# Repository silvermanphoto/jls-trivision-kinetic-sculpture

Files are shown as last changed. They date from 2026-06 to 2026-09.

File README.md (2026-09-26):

# Trivision Kinetic Sculpture

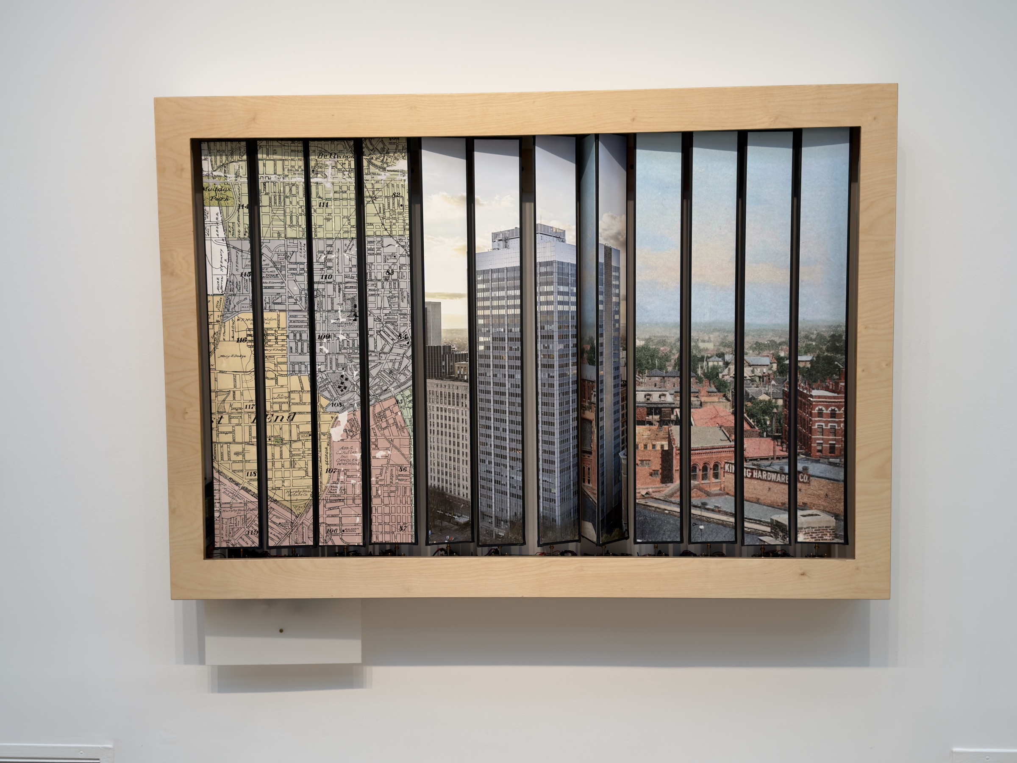
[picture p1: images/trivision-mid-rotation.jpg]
The sculpture mid-rotation: twelve prisms showing the map, the 2025 photograph, and the 1895 view at once


I found an 1895 carte-de-visite made about 800 feet away from Atlanta's "zero
mile post" which marked the founding spot of the city in 1837, and directly over
the site of Jacobs' Pharmacy where Coca-Cola was first served in 1886. A now
unknown photographer made the view from the rooftop of the now-demolished
original Equitable Building in Atlanta's Five Points. To capture the same
viewpoint, I had to figure out the rooftop height of that long-gone building,
and fly a drone camera to that elevation. The alignment of my 2025 photograph
with the 1895 postcard is almost perfect, yet there is almost no architectural
legacy left from the original scene, so I have paired the two photographs with
a map so the viewer can orient themselves.

Making the images rotate in the style of a 1950s trivision billboard came to me
when I was commissioned to create a 40 foot long immersive hallway for Hambidge
Hive in 2025. I created a zigzag in the style of a tabula scalata, an illusion
dating from the 16th century in which an image is painted on two faces of a
zigzag frame so that the picture seems to change from one image to another
while walking past it. I was happy/not happy with the result. I liked the idea
of activating an installation with the viewer's own participation. But I
wondered if a tabula scalata could reveal itself, and remembered vaguely that
in the 1950s there were "trivision" billboards on the highways that rotated ads
on prisms, the first "digital display" in history.

It took me six months of feverish work to figure out how to make the 12 motors
work in sync, and designing and fabricating the massive intricate plywood
cabinet it is housed in turned out to be one of the most fiendishly difficult
technical challenges of my studio career.

— Joel Silverman

## The sculpture

Twelve triangular prisms in a row, each carrying strips of three photographic
images, each turned by its own stepper motor inside a CNC-fabricated wooden
frame. As the prisms rotate — slowly, silently, in choreographed patterns — the
sculpture dissolves between three photographs; when all twelve prisms land on
the same face, a single panorama spans the full width.

A kinetic artwork by [Joel Silverman](https://joelsilverman.com), Atlanta,
choreographed like a musical score. Current image sets: *Blind Willie McTell*,
*Barnard Gulch*, and *Oakland Magnolia*.

## How it works

**Choreography is authored in Blender.** Each prism is a keyframed object in a
Blender scene. The plan is to extract the animation curves and convert them into
integer step/timing tables (`steps = degrees/360 × 3200` at 1/8 microstepping,
24 fps timebase) that compile straight into the Arduino firmware; the patterns
running today are written by hand in the firmware.

**One Arduino Mega 2560 drives all twelve motors.** Each prism has a NEMA 17
stepper (0.9°/step) on a TMC2209 silent driver. The proven motion architecture
runs a 50 µs Timer1 interrupt with integer S-curve acceleration tables and
direct port-register step pulses — no floating point and no `digitalWrite` in
the hot loop — so twelve axes stay smooth and the gallery stays quiet. Motion
is deliberately gentle: the authorized ceiling is 1 RPM.

**Power:** Mean Well LRS-150-24 supplies the motor rail; a buck converter feeds
the Mega. Full electronics detail, pin assignments, and the development history
live in `ARDUINO/TrivisionHandoff.md` — the canonical spec for this project.

## Repository contents

```
ARDUINO/                     all firmware, forked by version, never overwritten:
                             TrivisionChoreo_v7_* (live choreography family),
                             TrivisionHWTest_* (bring-up tests),
                             TrivisionCascade_* (4-motor prototype era),
                             plus motion simulators and TrivisionHandoff.md
CNC Fabrication Plans/       DXF/SVG cut files for the frame
ILLUSTRATOR FILES FOR CNC/   vector source for the cut files
Woodworking Frame Plans/     frame joinery drawings
3D Printing Files/           printed brackets and fittings
Stepper Motor 17HM19-2004S/  motor documentation and CAD
Trivision Kinetic Sculpture Manual-2.pdf   the printed manual
```

This repository tracks code, fabrication plans, and documentation. The heavy
project media (Blender scenes, photographic scans, renders, video) lives
outside git.

The wooden housings were cut with a companion tool also on GitHub:
[CNC-boxcreator](https://github.com/silvermanphoto/CNC-boxcreator), which
generates the CNC toolpath SVGs for the frame boxes.

## Status

A 4-motor prototype verified the motion architecture end to end (smooth S-curve
starts and stops at sub-1-RPM speeds, no resonance, inaudible at gallery
distance). The same engine now drives all twelve prisms on the sculpture: the
v7 choreography sketches turn them all together or in a waterfall. Blender
playback and hall-sensor homing are the next fronts; see
`ARDUINO/TrivisionHandoff.md` for the roadmap.

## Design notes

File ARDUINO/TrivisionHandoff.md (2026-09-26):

# TRIVISION KINETIC SCULPTURE — Agent Handoff Prompt

**Date:** February 23, 2026
**Author:** Joel Silverman (visual artist, college professor, photographer)
**Purpose:** Complete context transfer for an AI coding agent to continue development of Arduino-controlled kinetic art sculpture.

> **Status note, 26 September 2026.** This is the February 2026 spec. Its hardware, pin map, conversion math and homing design still hold; its status sections (which sketch family is current, what is uploaded, what is untested) are history. For current state read `git log`, `TMC2209 Wiring and Power Reference.html` in the project root and the arduino-expert skill; for what is on the board, read the serial banner at 115200 baud. Since February the twelve-motor Timer1 choreography (`TrivisionChoreo_v7_*`) has replaced `TrivisionCascade` and run on the sculpture, the STEP port map in Section 7 has been verified, and Section 7's interrupt budget has been replaced with figures counted from the compiled program.

---

## SECTION 1: WHAT THIS PROJECT IS

A 12-prism kinetic sculpture. Twelve triangular prisms are mounted in a row inside a CNC-fabricated wooden frame. Each prism is driven by an independent NEMA 17 stepper motor via a TMC2209 driver, all controlled by a single Arduino Mega 2560. The prisms rotate to display three different photographic images — when all 12 prisms show the same face, a single panoramic photograph is visible across the entire sculpture. Choreographed rotation sequences create animated transitions between the three images.

The animation choreography is authored in Blender and must be converted to stepper motor commands that preserve the exact timing, rotation amounts, and interpolation character of the Blender keyframes. This is gallery art — the motion must be hypnotic, gentle, and silent. The audience should never perceive the machinery.

---

## SECTION 2: BEHAVIORAL RULES (NON-NEGOTIABLE)

These rules govern how you operate on this project. Violating them will cause hardware damage or destroy weeks of work.

### Code Versioning
- **NEVER overwrite Arduino sketches.** Always fork to a new version before modifying.
- Naming convention: `SketchName_v01`, `SketchName_v02`, etc.
- **Confirm the version number with the user before writing any file.**

### Arduino Code Output
- Save all sketches via the Arduino MCP `write_file` tool.
- MCP sketch directory: `~/Documents/Arduino_MCP_Sketches/`
- Project archive directory: `/Users/joelsilverman/Desktop/2025 Files/25-033 Trivision Kinetic Sculpture/ARDUINO/`
- Save to both locations.
- The main choreography sketch family is `TrivisionCascade`. Hardware test sketches are `TrivisionHWTest`.

### Authority Hierarchy
1. **The Blender file** is the sole authority on animation/rotation data.
   - Path: `/Users/joelsilverman/Desktop/2025 Files/25-033 Trivision Kinetic Sculpture/Blender Files/`
   - Always list this directory, identify the `.blend` file (NOT `.blend1`, `.blend2` backups) with the highest version suffix, and confirm the exact filename with the user before extracting animation data.
   - The current highest-version file as of this writing: `TRIVISION new spacing MCTELL GULCH MAGNOLIA Blender v19.blend`
2. **The Google Drive hardware manual** is the authority on electronics, BOM, and fabrication.
   - URL: https://docs.google.com/document/d/13_A63P2TwJsc9UtIJb35i7quOOlHrLHadYizh7lsTQA/edit
3. **The Google Drive Python script** is reference for Blender geometry/UV/materials only — its animation data is outdated.
   - URL: https://docs.google.com/document/d/1jP-eXVxYtKtYfGwvMH7EY039DtjzSabbf-j0JPjw7dc/edit

### Blender Extraction Pipeline
- When extracting keyframes from Blender files, use the **Blender 5.0+ layered action API** (`action.layers → strips → channelbags → fcurves`), NOT legacy `fcurves`.

### Safety Philosophy
- When in doubt — especially about microstepping mode, wiring pin assignments, or any action that writes to hardware — **ASK rather than guessing.** Confirm before writing to hardware.
- **Speed is MISSION CRITICAL.** Never exceed speeds the user has explicitly authorized. This is an art installation with heavy, delicate prisms — no lurching, no racing, no sudden direction changes without deceleration to zero first.
- The user has described this as "hypnotic and gentle, not a lab centrifuge." Treat every speed and acceleration parameter as safety-critical.
- **Adjacent prisms may collide.** In the simulators' geometry a prism's corners sweep a circle wider than the shaft pitch, so neighbours at different angles can touch; the as-built pitch has not been measured. Only exact unison from square, or one prism at a time beside square neighbours, is known to be safe. Check any other pattern with `ARDUINO/prism_clearance.py` before upload, and after any rewiring confirm every motor turns the same way before running a sketch that moves more than one prism.

### User Preferences
- Never overwrite code without forking.
- Don't apologize when corrected — just fix it.
- Display web links as full readable URLs, not markdown link syntax.
- Preferred fonts: Futura, Gill Sans, Lato (never Arial).
- The user is a visual/conceptual artist, not a software engineer. Use clear, component-label-based instructions rather than technical abbreviations. When giving wiring instructions, reference physical labels on the boards.

---

## SECTION 3: HARDWARE SPECIFICATION

### Board
- **Arduino Mega 2560** with HCDC screw terminal shield
- FQBN: `arduino:avr:mega`
- Port: Check with `list_boards` before every upload — it can change between `usbmodem2101` and `usbmodem1101`
- Power: 9V from LM2596 buck converter to VIN, also USB during development

### Motors (×12)
- StepperOnline NEMA 17, model 17HM19-2004S
- 0.9° step angle = 400 full steps per revolution
- 2A rated current, 2.9V
- Bipolar, 4-wire

### Drivers (×12)
- Adafruit TMC2209 breakout boards (product 6121)
- StealthChop mode enabled (silent operation for gallery)
- MS1/MS2 floating = **1/8 microstepping** (this is the default and current operating mode)
- **3200 microsteps per revolution** (400 full steps × 8)

### Microstepping Math
- Each microstep = 0.1125°
- 120° rotation = 1067 steps (3200 / 3 = 1066.67, rounded to 1067)
- 240° rotation = 2133 steps
- 360° rotation = 3200 steps

### Pin Assignments (ALL CONFIRMED AND PHYSICALLY WIRED)

| Motor | STEP Pin | DIR Pin | Hall Pin (NOT WIRED) |
|---|---|---|---|
| 1 | 35 | 18 | 2 |
| 2 | 36 | 19 | 3 |
| 3 | 37 | 20 | 4 |
| 4 | 38 | 21 | 5 |
| 5 | 39 | 22 | 6 |
| 6 | 40 | 23 | 7 |
| 7 | 41 | 24 | 8 |
| 8 | 42 | 25 | 9 |
| 9 | 43 | 26 | 10 |
| 10 | 44 | 27 | 11 |
| 11 | 45 | 28 | 12 |
| 12 | 46 | 29 | 13 |

### Power
- **24V motor power:** Mean Well LRS-150-24 (fanless) → all driver VM/GND screw terminals
- **5V logic power:** Arduino Mega 5V → Electrocookie PCB bus rails → all driver VDD (pin 1) and GND (pin 2)
- **9V board power:** LM2596 buck converter (fed from 24V) → Arduino Mega VIN
- **Decoupling:** 100–470µF electrolytic cap on Electrocookie 5V/GND rails
- **Grounding:** All domains (Arduino, drivers, power supplies) share common ground

### Power-On Sequence
1. Upload sketch via USB first (Mega powered by USB alone)
2. Open Serial Monitor at 115200 baud, confirm startup banner
3. Then apply 24V (plug in Mean Well)
4. Press the Mega's reset button, so a sketch that starts moving on its own begins with the drivers powered (lesson 4 in Section 6). A test sketch that waits for a command needs no reset.
5. Mega can safely receive power from both USB and VIN simultaneously

### Hall Effect Sensors (NOT YET INSTALLED)
- A3144 (EPLZON brand), one per prism
- Digital output, active LOW when magnet detected
- Pins 2–13 reserved but **not wired and not to be touched in code** until the user says otherwise

---

## SECTION 4: CONVERSION MATH (BLENDER → ARDUINO)

### Rotation
```
steps = (degrees / 360) × 3200
```

### Timing
```
seconds = frames / 24    (Blender scene is 24 FPS)
```

### Interpolation Types
- **CONSTANT keyframes** = instant position holds (the prism teleports — in practice, move as fast as safely possible)
- **BEZIER keyframes** = acceleration-profiled moves (smooth ramp up, cruise, ramp down)

### Speed Reference
| RPM  | Steps/sec | Time for 1 rev | Time for 120° | Character |
|---|---|---|---|---|
| 0.5  | 26.67 | 120 sec | 40 sec | Meditative, glacial |
| 1.0  | 53.33 | 60 sec | 20 sec | Slow clock hand |
| 2.0  | 106.67 | 30 sec | 10 sec | Gentle gallery motion |
| 5.0  | 266.67 | 12 sec | 4 sec | Purposeful |

**Currently authorized maximum: 1 RPM unless the user explicitly raises it.**

---

## SECTION 5: MISSION-CRITICAL REQUIREMENTS (FUTURE IMPLEMENTATION)

These are not yet implemented but define the target architecture. Do not implement without user direction — this section is reference for understanding the design intent.

### Homing Procedure
- Every power-on and periodically during operation, all 12 prisms must home to a known zero position using Hall Effect sensors.
- Drift is unacceptable — the images must align across all 12 prisms.

### Hold Position (Re-home Trigger)
- Defined as: all 12 motor step queues empty and no motor currently stepping.
- Occurs between choreography transitions when every prism is stationary at a target angle (0°, 120°, 240°, or 360°).
- Re-home window: interval between the last prism arriving at its hold angle and the first prism departing for the next transition.
- Re-home all prisms sequentially (not simultaneously) during this window.

### Graceful Sensor Failure Handling
- **Homing timeout:** If a prism doesn't find its Hall sensor within 1.5 full revolutions (540°), mark as FAULT, stop that motor, continue with the other 11. Report via Serial.
- **Sensor disconnect mid-run:** Open-loop step counting is primary position tracker during choreography. Hall sensors are for periodic drift correction only. A disconnected sensor means that prism loses drift correction but keeps running.
- **Periodic re-home:** Between choreography cycles, attempt a soft re-home — rotate slowly toward expected Hall trigger. If confirmed within ±5° of expected position, correct. If not found, flag drift warning but do not abort.
- **Status reporting:** Per-prism status array (OK, DRIFT_WARNING, SENSOR_FAULT). Print status on every re-home cycle via Serial.
- **Degraded mode:** Sculpture continues operating with any number of faulted sensors. Only a faulted motor (stall detection via TMC2209 diag pin) should stop that prism.

### Core Design Philosophy
Hall sensors correct drift, step counting drives position. The sculpture never depends on a sensor being present to know where it is — it always knows where it should be. The sensor just confirms it.

---

## SECTION 6: DEVELOPMENT HISTORY AND CURRENT STATE

### Sketch Families

**TrivisionCascade series (v01–v15):** Choreography development on a 4-motor prototype.
- v01: Single-motor hello world test. Raw `delayMicroseconds()` stepping with linear trapezoidal ramp. Proved basic hardware works.
- v02–v08: Progressive multi-motor cascade development using AccelStepper library. Encountered visible stuttering issues due to floating-point math in the step timing loop.
- v09–v14: Transition to timer-interrupt-driven architecture to eliminate jitter. Moved from `AccelStepper` polling to Timer1 ISR at 50µs tick rate with pre-computed integer ramp tables and direct port register manipulation for step pulses.
- **v15 (latest choreography sketch):** 4-motor cascade with zero-jitter Timer1 ISR. Pattern: cascade CW 180° (motors 1→2→3→4 with 1.25s stagger) → hold 3s → reverse CCW 180° (4→3→2→1) → hold 3s → repeat. Uses direct port writes (`PORTC`, `PORTG`) for ~125ns step pulses. Pre-computed S-curve ramp tables (250-step ramp, 70→22 tick range). This is the proven smooth-motion architecture.

**TrivisionHWTest series (v01–v03):** 12-motor hardware verification on the full sculpture.
- v01: Sequential test of all 12 motors — forward 2 revolutions, pause 15s, backward 1 revolution. 5-second stagger, 1 RPM, AccelStepper with trapezoidal ramp. All 12 motors confirmed operational.
- v02: Continuous forward rotation at 0.5 RPM, all 12 motors, endless loop.
- **v03 (currently uploaded and running):** Each prism rotates BACKWARD 120° at 0.5 RPM, pauses 10 seconds, repeats forever. 5-second stagger. AccelStepper with acceleration profiling.

### Key Technical Lessons Learned
1. **Floating-point math in step-generation loops causes visible stuttering.** The Arduino's FPU-less AVR takes variable time to compute float operations, creating timing jitter that manifests as audible and visible motion artifacts. Solution: pre-compute all timing values as integer tick counts in lookup tables, drive stepping from a fixed-rate timer ISR.
2. **AccelStepper's `run()` function works well at slow speeds (≤2 RPM)** where the polling interval is long relative to the `loop()` cycle time. At higher speeds or with many motors, the polling approach introduces jitter. For the final choreography at gallery speeds, the Timer1 ISR approach from v15 is the proven solution.
3. **Direct port register manipulation** (`PORTx |= (1 << bit)`) generates step pulses in ~125ns vs. `digitalWrite()` at ~6µs. Critical for the ISR approach where multiple motors must be serviced within a single 50µs tick.
4. **The stagger timing bug:** When the sketch boots via USB upload but motors don't have 24V power yet, the stagger countdown runs during the power-off period. By the time 24V arrives, all stagger windows have passed and all motors start simultaneously. Solution: either reset the Mega after applying 24V, or add a "wait for first step command" gate.

### What's Been Verified on Hardware (as of Feb 23, 2026)
- All 12 motors respond to STEP/DIR signals ✓
- All 12 TMC2209 drivers operational in StealthChop mode ✓
- Direction control (CW/CCW) works on all 12 ✓
- 3200 steps = 1 revolution confirmed ✓
- 1067 steps = 120° confirmed ✓
- Smooth acceleration ramp (no lurching) at 0.5 and 1.0 RPM ✓
- 24V power distribution to all 12 drivers ✓
- 5V logic distribution to all 12 drivers ✓
- No thermal issues observed during extended operation ✓

### What Has NOT Been Tested Yet
- Speeds above 1 RPM on the full 12-motor assembly
- Timer1 ISR approach on 12 motors (only tested on 4-motor prototype)
- Hall effect sensor homing (sensors not physically installed)
- Choreography playback from Blender keyframe data on 12 motors
- Extended multi-hour continuous operation

---

## SECTION 7: ARCHITECTURE NOTES FOR 12-MOTOR ISR EXPANSION

The v15 Timer1 ISR architecture was proven on 4 motors using direct port register writes. Expanding to 12 motors requires mapping all 12 STEP pins to their AVR port registers:

| Motor | STEP Pin | AVR Port | Bit |
|---|---|---|-----|
| 1 | 35 | PORTC.2  | 2 |
| 2 | 36 | PORTC.1  | 1 |
| 3 | 37 | PORTC.0  | 0 |
| 4 | 38 | PORTD.7  | 7 |
| 5 | 39 | PORTG.2  | 2 |
| 6 | 40 | PORTG.1  | 1 |
| 7 | 41 | PORTG.0  | 0 |
| 8 | 42 | PORTL.7  | 7 |
| 9 | 43 | PORTL.6  | 6 |
| 10 | 44 | PORTL.5  | 5 |
| 11 | 45 | PORTL.4  | 4 |
| 12 | 46 | PORTL.3  | 3 |

**Verified (September 2026):** all twelve rows above match `variants/mega/pins_arduino.h` in ArduinoCore-avr, the table the compiler itself uses. The February note here asked for this check against the pinout PDF; it is closed.

The ISR must service all 12 motors within the 50µs tick window: 800 CPU cycles at 16MHz. The February estimate here (20–30 cycles a motor, 240–360 in all) was 3 to 10 times too low. Counted from the compiled v7.10 interrupt at ATmega2560 instruction timings (September 2026 code review, finding TRI-08):

| Case | Cycles | Time |
|---|---|---|
| Fixed cost per tick (entry, 22 registers saved and restored) | 131 | 8 µs |
| Each idle motor | 24 | |
| Each running motor that does not step | 41 | |
| Each motor that steps (two runtime shift loops for `1 << stepBit[m]`, 32-bit volatile reloads, struct address recomputed with two multiplies) | 196–276 | |
| Nothing moving | 418 | 26 µs, 52% of the processor |
| Twelve running, none stepping | 622 | 39 µs |
| All twelve stepping on the same tick, as the all-together pattern does | 2,884–3,028 | 180–189 µs, 3.6–3.8 ticks |

Harmless at 0.75 RPM: each all-step tick drops two Timer1 compare matches, but the lost time delays every motor equally, so sync holds and the pattern runs about 0.4% slow. `loop()` gets 48% of the processor with nothing moving and 22% while twelve motors run, less than the design assumed, and the STEP pulse is high for 2.3–4.5 µs. Plan any added interrupt work (Hall-sensor checks, per-prism Blender tables) or higher speed against these figures. If headroom is needed: store step masks instead of bit numbers (removes both shift loops), copy each motor's fields into locals once per tick and write back once, use `uint16_t` step counts (never above 3200), and compute `decelStart` at launch. Confirm with a spare pin toggled on ISR entry and exit and a scope.

---

## SECTION 8: REFERENCE DOCUMENTS

### In This Claude Project (uploaded PDFs)
- `TMC2209_datasheet_rev1_09.pdf` — Driver IC datasheet
- `A000067datasheet.pdf` — Arduino Mega 2560 datasheet
- `A000067fullpinout.pdf` — Mega 2560 complete pinout diagram
- `A000067schematics.pdf` — Mega 2560 board schematics
- `17HM192004S_Full_Datasheet.pdf` — NEMA 17 motor specs
- `17HM192004S_Torque_Curve.pdf` — Motor torque curves
- `lrs150.pdf` — Mean Well LRS-150-24 power supply datasheet
- `EPLZON_3Pins_A3144...` — Hall effect sensor specs
- `Screenshot_20260222_at_8_11_12_PM.png` — Photo of HCDC screw terminal shield

### On Google Drive
- Hardware Manual: https://docs.google.com/document/d/13_A63P2TwJsc9UtIJb35i7quOOlHrLHadYizh7lsTQA/edit
- Blender Generation Script (geometry/UV reference only, animation data outdated): https://docs.google.com/document/d/1jP-eXVxYtKtYfGwvMH7EY039DtjzSabbf-j0JPjw7dc/edit

### On Filesystem
- Blender files: `/Users/joelsilverman/Desktop/2025 Files/25-033 Trivision Kinetic Sculpture/Blender Files/`
- Arduino sketches: `/Users/joelsilverman/Desktop/2025 Files/25-033 Trivision Kinetic Sculpture/ARDUINO/`
- MCP sketches: `~/Documents/Arduino_MCP_Sketches/` (TrivisionCascade_v01–v15, TrivisionHWTest_v01–v03)

### Web References
- Arduino Mega 2560 docs: https://docs.arduino.cc/hardware/mega-2560/
- Motor product page: https://www.omc-stepperonline.com/nema-17-bipolar-0-9deg-46ncm-65-1oz-in-2a-2-9v-42x42x48mm-4-wires-17hm19-2004s
- TMC2209 breakout (Adafruit 6121): https://www.adafruit.com/product/6121
- HCDC screw terminal shield: https://www.amazon.com/dp/B0F1M24KG3

---

## SECTION 9: NEXT STEPS (PROBABLE)

These are likely upcoming tasks based on the project trajectory. The user will direct which to pursue:

1. **Extract keyframe data from the Blender v19 file** and convert to a step/timing table for all 12 prisms.
2. **Expand the Timer1 ISR architecture from v15 to 12 motors** with correct port register mappings for all 12 STEP pins.
3. **Build a choreography playback engine** that reads the Blender-derived step/timing table and executes it on all 12 motors with the proven zero-jitter ISR approach.
4. **Install and integrate Hall effect sensors** for homing and periodic drift correction, following the graceful failure architecture described in Section 5.
5. **Long-duration reliability testing** — the sculpture must run unattended for hours in a gallery setting.

---

*End of handoff document.*

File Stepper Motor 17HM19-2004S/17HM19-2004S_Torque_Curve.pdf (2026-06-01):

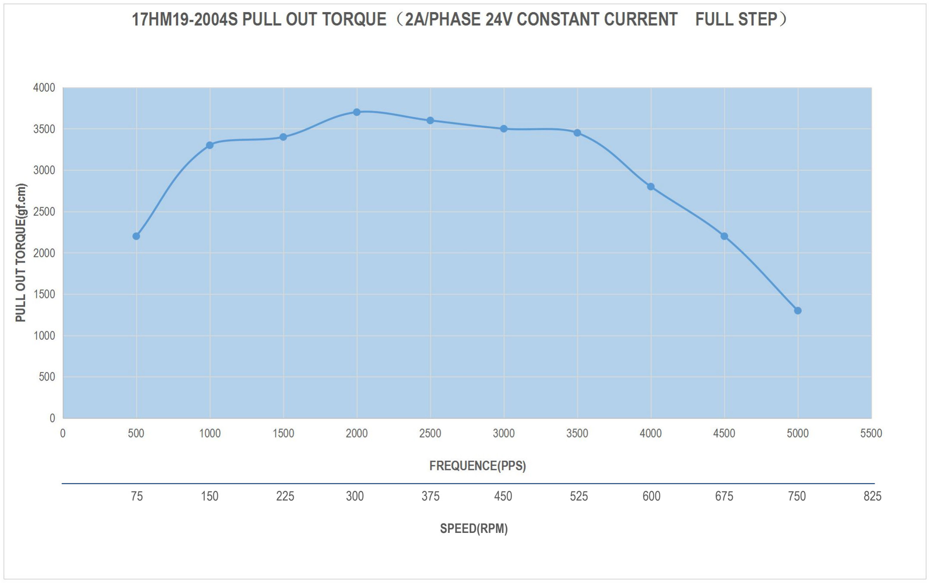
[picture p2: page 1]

75 | 150 | 225 | 300 | 375 | 450 | 525 | 600 | 675 | 750 | 825
| | | | | SPEED(RPM)

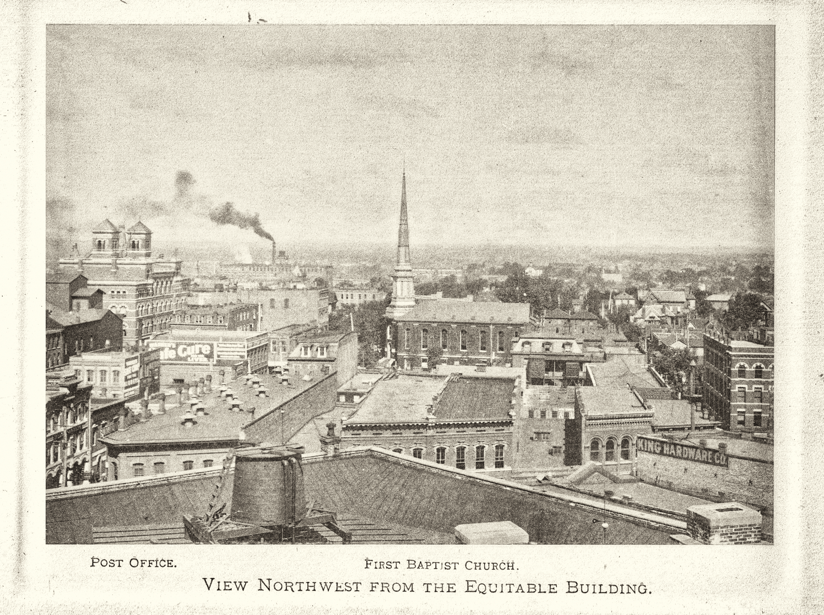
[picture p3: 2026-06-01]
Woodworking Frame Plans/Screenshot 2025-11-29 at 10.19.41 PM.png

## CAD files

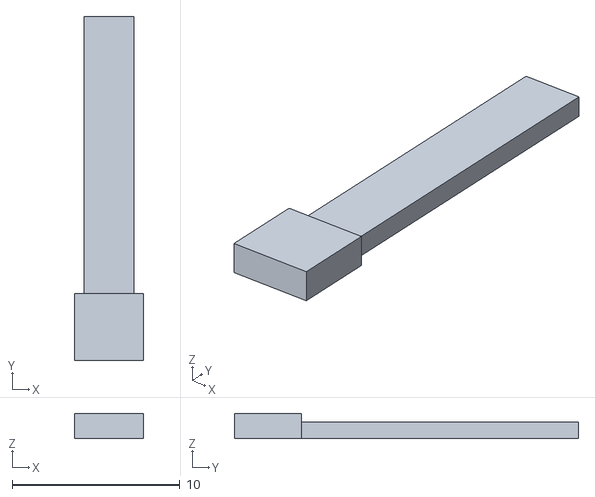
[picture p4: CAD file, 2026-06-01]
3D Printing Files/Negative Hall Shape.stl
4.10 x 20.5 x 1.50

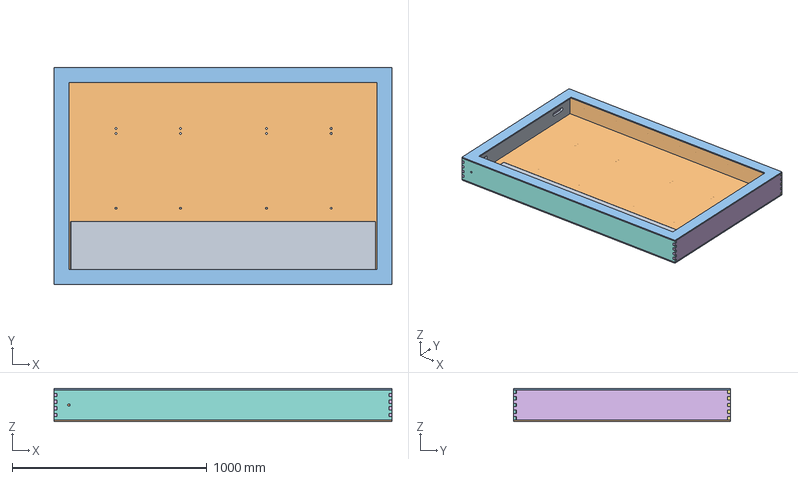
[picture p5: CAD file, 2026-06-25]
CNC Fabrication Plans/06.02.26 Pegleg Studio Trivision File PLS NEW.step
1733.6 x 1115.2 x 170.1 mm
Inner Side (1)
Top Liner (1)
Bottom Liner (1) (1)
Inner Side (1) (1)
Outer Side (1)
Outer Side
Outer Top (1)
Outer Bottom (1)
Access Panel (1)
Front Frame (1)

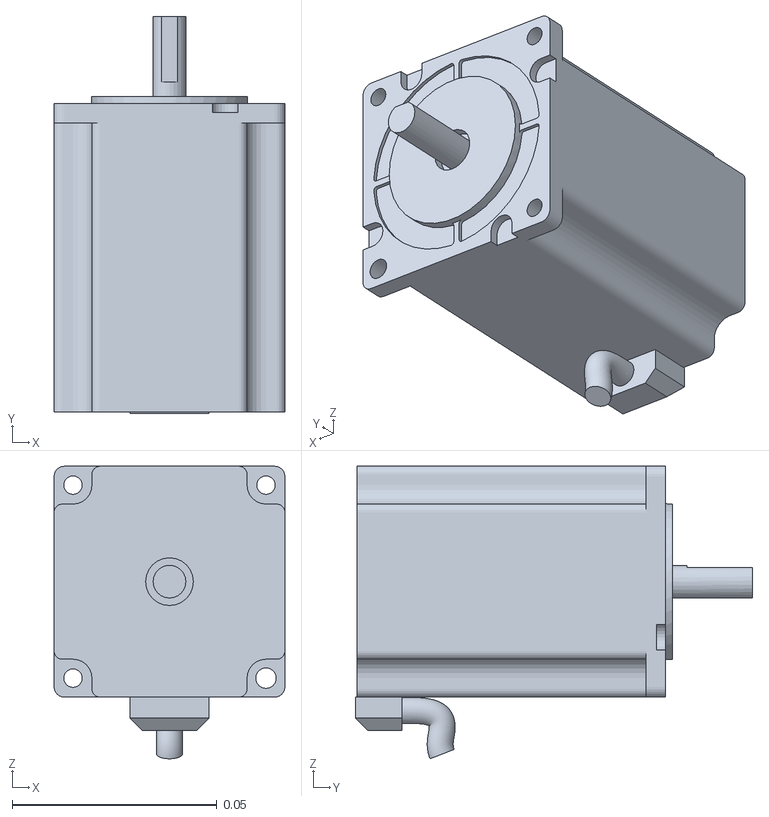
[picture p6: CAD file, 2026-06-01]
Stepper Motor 17HM19-2004S/Nema 23.obj
0.0564 x 0.097 x 0.0715

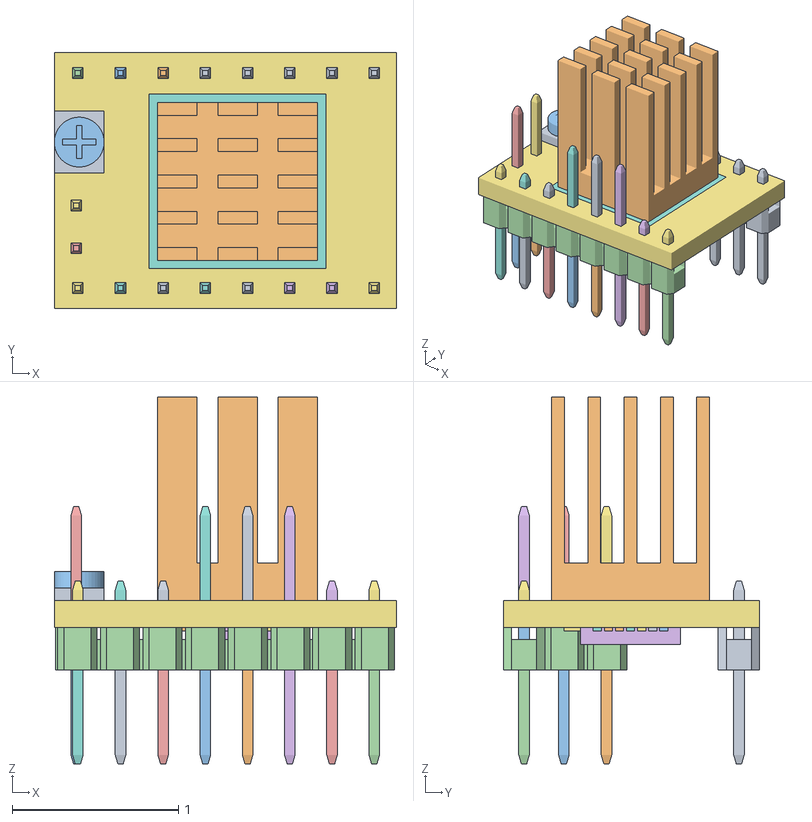
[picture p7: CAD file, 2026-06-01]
Woodworking Frame Plans/BTT TMC2208 TMC2209 UART Stepper Driver.obj
2.06 x 1.54 x 2.21
Header Main Body
Pin (For adding more Pins)
Pin (For adding more Pins) (1)
Pin (For adding more Pins) (2)
Pin (For adding more Pins) (3)
Header Main Body (1)
Header Main Body (3)
Pin (For adding more Pins) (2) (1)
Pin (For adding more Pins) (1) (1)
Header Main Body (2)
Header Main Body (4)
Header Main Body (5)
Header Main Body (6)
Header Main Body (7)
Pin (For adding more Pins) (2) (4)
Pin (For adding more Pins) (1) (4)
Pin (For adding more Pins) (6)
Header Main Body (8)
Header Main Body (10)
Header Main Body (12)
Header Main Body (14)
Header Main Body (22)
PCB (1)
PCB (2)
Pin (For adding more Pins) (2):1
Pin (For adding more Pins) (3):1
Pin (For adding more Pins) (3) (1)
Pin (For adding more Pins) (3) (1) (1)
Pin (For adding more Pins) (3) (1) (2)
Pin (For adding more Pins) (3) (1) (3)
Pin (For adding more Pins) (2) (1):1
Pin (For adding more Pins) (1) (1):1
Pin (For adding more Pins) (2) (4):1
Pin (For adding more Pins) (1) (4):1

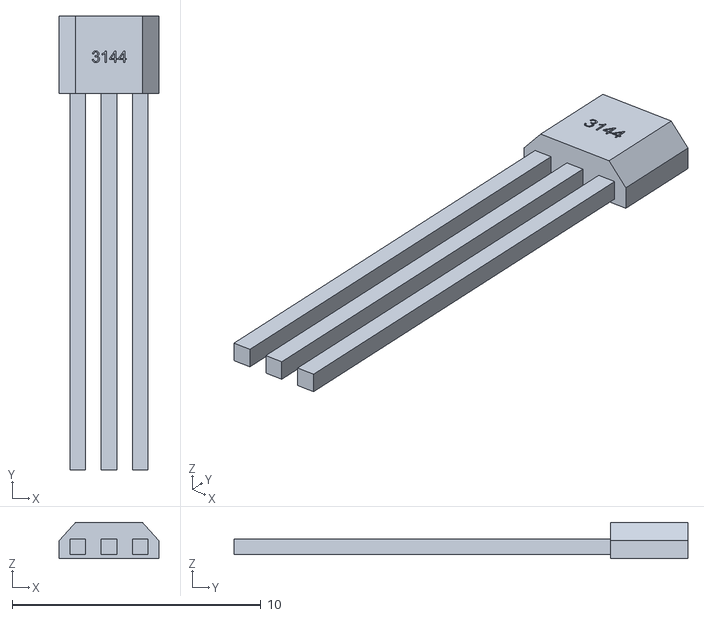
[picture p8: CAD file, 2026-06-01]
3D Printing Files/A3144 Hall Effect Sensor.obj
4.00 x 18.2 x 1.46

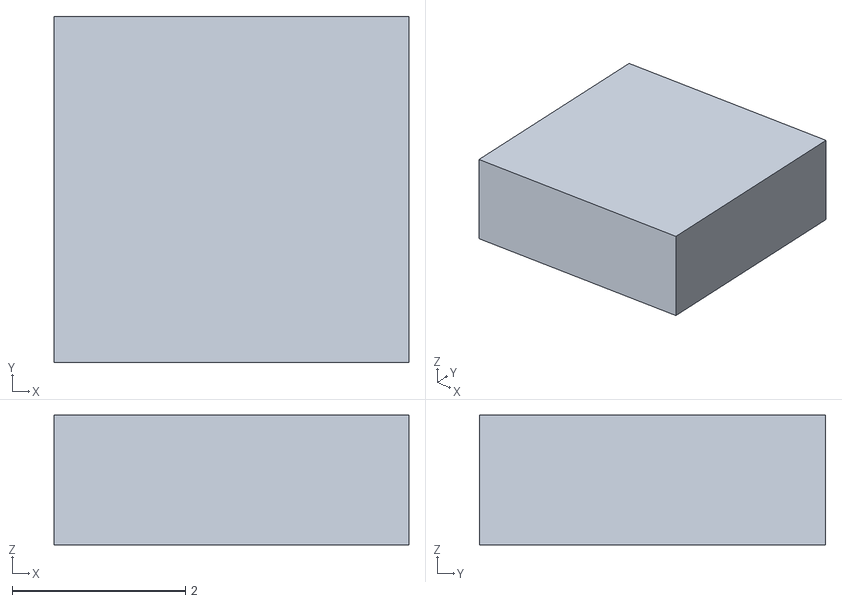
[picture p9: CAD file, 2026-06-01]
3D Printing Files/Negative Hall Head.stl
4.10 x 4.00 x 1.50

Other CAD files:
ILLUSTRATOR FILES FOR CNC/Silverman Dibond Origami Prism Stephen 36in v2.dxf
CNC Fabrication Plans/PEGLEG Trivision PLS.dwg
CNC Fabrication Plans/PEGLEG McTell 40x40 PLS.dwg
CNC Fabrication Plans/02.13.26 Updated Inner Frame with Gap v4.dxf
CNC Fabrication Plans/TRIVISION FRAME master file v3.dwg

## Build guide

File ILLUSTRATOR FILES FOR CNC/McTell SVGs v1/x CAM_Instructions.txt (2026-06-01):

Project: McTell Ghostphone Shadowbox
Generated: 2026-01-02 04:07:41
Active Joinery Method: HALF_ROUND_BOX_JOINT

CUT LIST (Name | Qty | Dimensions):
1. FRONT_BEZEL | 1 | 63.46" x 44.58"
See previous version for full CAM details. Parameters applied.

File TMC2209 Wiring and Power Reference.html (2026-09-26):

# Trivision — driver wiring and power reference

Adafruit TMC2209 breakout · StepperOnline 17HM19-2004S · Mean Well LRS-150-24
Prepared 26 July 2026, after the rewiring · current-dial figures corrected 29 July 2026

## The green screw terminal, left to right

Six terminals. The first two are power in from the Mean Well — no motor wire ever goes there. Only the right-hand four take motor wires.

+

24V in
not a motor wire

−

ground in
not a motor wire

2B

BLUE

2A

RED

1A

BLACK

1B

GREEN

Across the four motor terminals the colours run blue, red, black, green.

### Why those pairings

The motor has two separate coils. Terminals 1A and 1B are the two ends of one coil; 2A and 2B are the two ends of the other. Wires from different coils must never share a pair.

Wire | Coil end | Terminal | Partner
Black | A+ | 1A | pairs with green
Green | A− | 1B | pairs with black
Red | B+ | 2A | pairs with blue
Blue | B− | 2B | pairs with red

Source: the motor's own datasheet, 17HM19-2004S_Full_Datasheet.pdf, page 1, "Motor Connection" table. Terminal meanings from Adafruit's TMC2209 pinout documentation.

Swapping a pair reverses the motor

If you reverse the two wires within one coil — black and green with each other, say — the motor runs normally but turns the other way. Only mixing wires between the two coils causes a fault. On this sculpture a reversed motor is not harmless: in a sketch that turns every prism together, a reversed prism turns against its neighbours, and neighbouring prisms may touch. Correct a reversed prism in software before running any sketch that turns more than one prism at a time.

## The other side — the pin header to the Arduino

Checked against your wiring manual, the four-wire cable from the Arduino is correct as built:

Cable colour | Driver pin | Goes to
Red | VDD | 5V logic bus
Yellow | GND | ground bus
Green | DIR | Arduino terminal 18–29
White | STEP | Arduino terminal 35–46

Two different green wires

Green on the pin header means direction. Green on the screw terminal means one end of motor coil A. They are unrelated and go to different connectors — worth keeping straight when tracing a cable.

### Leaving the remaining pins unconnected — mostly right, one worth changing

Your manual records MS1, MS2, DIAG, INDEX, UART and EN as unconnected on every driver. Two of those are exactly right:

Pin | Left unconnected | Result
EN | fine | Driver enabled. Adafruit's guide: "pull this pin high to disable the output to the motors," so floating leaves it running.
MS1, MS2 | fine | 1/8 microstepping, the board's default — 3200 microsteps per revolution, which is what the sketch's step maths assumes.
UART (header pin 9) | worth changing | This is also the automatic standstill power-down control. Floating means the feature is not reliably on. Grounding it cuts resting power to under a third — see the section below.

So none of these is the source of the pulsing, but one of them is leaving a large power saving on the table.

## Verify by meter, not by colour

After a rewiring, an extension lead may have been swapped and the colours can lie. With the 24V off, measure resistance between wire ends:

Between | Should read | Meaning
Black and green | about 1.45 Ω | these two are one coil
Red and blue | about 1.45 Ω | these two are the other coil
Black and red | open circuit | different coils, correctly isolated

Any pair reading near 1.45 ohms is a coil. Any pair reading open is across two different coils. The 1.45 ohm figure is the resistance-per-phase from the datasheet.

## Setting the current dial, and knowing the number in advance

Corrected 29 July 2026 after reading Adafruit's schematic for this exact board. The figures further down this page were wrong; they are fixed here.

The little dial sets a reference voltage that tells the chip how much current to push through the motor. You can read that voltage with a multimeter and set it deliberately instead of guessing.

### Where to put the probes

The dial is a Bourns 3314J trimmer. Its body and its adjustment slot are plastic and connected to nothing — touching them reads zero no matter what else is right. The three tiny metal legs soldered to the board are the only electrical contacts.

Hold the board with the green screw terminal at the top and the row of pins at the bottom, looking down at the component side. The dial sits on the right-hand edge, and its three legs are arranged two-and-one:

Leg | What it is | Should read
The single leg, pointing up toward the screw terminal | The measuring point — this is the wiper | 0 to 1.16 V, moves as you turn the dial
Of the two legs pointing down toward the pins: the one nearer the board's edge | The fixed feed into the dial | 1.16 V, always
Of the two legs pointing down: the one nearer the chip | Ground | 0 V

1. Unplug that driver's motor at the green screw terminal first. Then nothing can move while you work. Nothing on or around the dial is at a dangerous or damaging voltage, so this part is low-risk.
2. Apply 24 V — and confirm it is really there. See the warning below; this is the most likely reason for a zero reading.
3. Black probe on ground. The ground screw terminal on the green block (second from the left, marked with a minus) is the easiest solid contact.
4. Red probe on the middle leg nearer the board's edge first — the fixed feed. If that reads 1.16 V, everything upstream is working and you can trust what you read on the wiper. If it reads zero, stop: the driver's internal 5 V is not running, which means 24 V is not reaching this board.
5. Meter on DC volts, 2 V range if it does not auto-range.

The lit LED does not mean 24 V is present

Read from Adafruit's schematic: the three little lights are logic indicators fed from the Arduino's 5 V, not power indicators. The red and green pair show which way the direction wire is set — green for one way, red for the other — and the yellow one flickers when step pulses arrive. All three run whether or not 24 V is connected.

So a light coming on tells you the Arduino is talking to the board. It says nothing about the motor supply. The dial's voltage, by contrast, comes from a 5 V regulator inside the driver chip that only runs when 24 V is on the board's power terminals.

Check 24 V directly at the two left-hand screw terminals on the green block, which is a far easier target than the dial's legs. If that reads 24 V and the dial's fixed leg still reads zero, that driver chip has a problem.

### The number to aim for

Current you want, per phase | Set the dial to
0.8 A | 0.61 V
1.0 A | 0.76 V
1.3 A — recommended | 1.00 V
1.5 A | 1.14 V
dial fully clockwise | ≈ 1.16 V ≈ 1.53 A

Each of the twelve dials is independent and they will not match out of the box. Setting all twelve is twelve measurements — about fifteen minutes, done once.

Why 1.00 V and not lower

The chip's own datasheet cautions against running the reference below roughly one volt: at low reference voltages, electrical noise and supply ripple become large relative to the reference, and the current regulation gets less precise. Their words: it is "not advised to work with reference voltages below about 0.5V to 1V for full scale," and for best precision a board should be designed so its maximum lands between 2 and 2.4 volts.

Adafruit's board tops out at 1.16 V, so it already sits inside the range the chip maker cautions about. Nothing to be done about that — it is fixed by resistors on the board. But it does mean the sensible move is to use more of the dial's range rather than less. Since imprecise current regulation shows up as chopper noise, and this piece has to be silent, the earlier advice to drop to 0.76 V was pointing the wrong way. Use 1.00 V, and take the heat saving from the standstill setting below instead.

## The one free change worth making: standstill power down

Grounding a single pin on each driver cuts the sculpture's resting power to under a third, with no loss of speed, smoothness or precision while moving.

A stepper burns its full set current while standing perfectly still, doing nothing. The TMC2209 has a built-in answer: when it notices the step pulses have stopped, it drops to a little over half current. The datasheet puts the saving at less than 33% of standstill power dissipation.

It is enabled by pulling the chip's combined power-down and serial pin to ground. Adafruit's schematic shows that pin wired only to the header — no pull resistor either way, so on your boards it is floating and the feature is not reliably on. Your wiring manual lists it as unconnected, which matches.

The change: a jumper from pin 9 of the ten-pin header to pin 2 (ground) on each driver. Pin 1 is the end nearest the 5 V logic wire; both are on the same connector you already have wires in, so nothing needs unsoldering.

Twelve motors | Standing still now | Standing still with the pin grounded
dial at 1.00 V (1.3 A) | ≈ 82 W | ≈ 27 W
dial fully clockwise (1.53 A) | ≈ 112 W | ≈ 37 W

Test this before trusting it

Half current at rest means half the holding torque at rest. If the prisms are well balanced about their shafts, gravity asks almost nothing of the motor and this is free. If any prism is heavy on one side, it could creep off its face while idle — which on this piece would be visible and unacceptable.

So do it on one driver first, leave that prism parked on a face for an hour, and check it has not drifted. Only then do the other eleven. Note also that grounding this pin rules out ever talking to the driver over its serial interface, which this project does not use.

Ignore the formula you will find online

Every guide on the internet assumes a current-sensing resistor of 0.11 ohms, because that is what the cheap 3D-printer driver boards use. Adafruit's board uses 0.05 ohms — components R1 and R2 in their published schematic, "0.05Ω/0.25W". Following the internet's numbers sets roughly 50% more current than intended.

The working figure for this board: current in amps = 1.31 × the voltage you measure, or turned round, volts = 0.76 × the current you want.

The dial cannot reach 2 amps

Adafruit feeds the dial through a fixed divider — 33 kΩ from the chip's 5 V regulator into a 10 kΩ trimmer — so the dial's full travel spans zero to about 1.16 volts, which is about 1.5 amps per phase. Adafruit's "up to 2A max" quotes the peak of the current waveform, about 2.16 amps, which is a different number from the one a motor is rated at.

Sources: Adafruit's published schematic for this breakout (R1, R2 = 0.05 Ω; 33 kΩ into a 10 kΩ trimmer off the chip's 5VOUT pin) and the TMC2209 datasheet current-setting equation.

## Why all twelve motors pulse on power-up

Not yet settled. The supply-overload explanation below was built on a current figure the hardware cannot actually reach, so it is weaker than it first appeared.

What is still solid:

1. The identification sketch on the Arduino sends no step pulses at all until you type a command. Nothing in the code is telling the motors to move.
2. All twelve pulse together. A wiring mistake affects one motor. Twelve motors moving in unison share only two things — the power rail and the control lines.
3. The Mean Well LRS-150-24 does protect itself in hiccup mode: on overload it shuts down, waits, and retries. Every retry would jolt all twelve motors at once.

### The corrected arithmetic

A microstepping driver holds a constant current vector at standstill, so the two coils share it rather than each carrying the full set current. The heat in one motor is the set peak current squared, times the winding resistance — not twice that.

Current per phase | Whole sculpture, standing still | Against a 156 W supply
1.53 A — dial fully clockwise, the true maximum | ≈ 110–120 W | about three-quarters loaded — tight, not a trip
1.3 A — recommended dial setting | ≈ 82 W | comfortable
1.3 A and standstill power-down grounded | ≈ 27 W | the setting to aim for
2.0 A | (≈ 155 W) | the dial cannot reach this

Overload protection engages at 110–140% of rating, which is 172–218 watts. Even with every dial at maximum the sculpture standing still does not get there. The driver-loss share of those figures is estimated from the chip's on-resistance rather than measured, so treat the range as a range.

So the dials are worth setting deliberately for heat and headroom — but they are probably not the cause of the pulsing on their own. Note too that when all twelve prisms move together, current is back to the full run figure, so the standstill saving does not help during a synchronised move.

The other candidate

If 24 V arrives while the Arduino is unpowered or held in reset, its twelve step and direction outputs are switched off. Noise on a step line is a step command, so floating lines could make all twelve motors twitch at once just as convincingly as a supply hiccup. The lines do not float, though. Adafruit's schematic for this board puts a 20 kΩ resistor from the step input to ground, and the driver chip holds its direction input low with a built-in resistor (datasheet rev 1.09, section 2.2). That makes this the less likely cause. The established power-on order keeps it out of the way regardless: USB first, confirm the serial banner, then 24 V. The reset press that now ends that order switches the Arduino's outputs off for a moment, and the same resistors hold the lines low through it.

## What to do, in order

1. Watch the rail — this one measurement decides it. Put a meter across the 24 V output while it pulses. If the voltage collapses and recovers in time with the pulsing, it is the supply. If the voltage holds steady, the supply is innocent and the cause is on the signal side.
2. Check the power-on order. Confirm the Arduino is powered and running the sketch — serial banner visible — before 24 V goes on. If the pulsing only happens when 24 V leads, that is the answer.
3. Prove it in two minutes. Unplug eleven motors at the terminal blocks and leave one connected. Power up. If the pulsing stops, it points at the shared rail rather than the wiring.
4. Set the current dials deliberately using the voltage table above — 1.00 V on each, giving about 1.3 amps per phase.
5. Ground the standstill power-down pin on one driver, confirm that prism holds its face for an hour, then do the other eleven. That is the large, free power saving.
6. Bring them back one at a time. Reconnect motors in small groups, checking after each that the supply stays steady.
7. Then run the identification sweep to sort out which channel drives which prism.

Your own design notes

The wiring manual states: "The system is calculated to draw ~80W under normal load. The 150W PSU provides ~50% safety headroom." Eighty watts across twelve motors is about 1.5 amps each. That is the top of what the dial can do, and the supply was chosen sensibly for it.

A note on the black-and-red theory

Swapping black and red would not produce this symptom. The two coils are electrically separate, so connecting one wire from each coil to the same bridge leaves that bridge with no circuit at all. A motor wired that way sits dead and silent — it does not buzz. Worth confirming with the meter regardless, but it is not what you are seeing.

Sources — motor: 17HM19-2004S_Full_Datasheet.pdf in this project folder. Driver: Adafruit TMC2209 breakout pinouts (https://learn.adafruit.com/adafruit-tmc2209-stepper-motor-driver-breakout-board/pinouts), and the board's own schematic — Adafruit-TMC2209-Breakout-PCB (https://github.com/adafruit/Adafruit-TMC2209-Breakout-PCB) — which is where the 0.05 Ω sense resistors and the 33 kΩ / 10 kΩ dial divider were read. Chip: TMC2209 datasheet rev 1.09 (https://www.analog.com/media/en/technical-documentation/data-sheets/TMC2209_datasheet_rev1.09.pdf), current-setting equation. Supply: Mean Well LRS-150 series specification (https://www.meanwell.com/Upload/PDF/LRS-150/LRS-150-SPEC.PDF).

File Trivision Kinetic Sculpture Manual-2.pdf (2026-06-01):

Trivision Kinetic Sculpture Manual

last revision Nov. 29, 2025

Status: Design & Specification Phase

I. Project Overview

This project details the design and fabrication of a parametric kinetic sculpture based on a "Trivision Billboard"(Rotating Agamograph) mechanic. It is a mechanical display for three distinct images, interlaced and mapped onto 12 rotating triangular prisms.

Primary prism starting size will be 4.25” wide x 36”tall (52” wide total for 12 prisms, and 62” wide artwork)

5.667” wide faces with 48”tall prisms for a giant museum-sized piece

Any 1:8.5 aspect ratio size strip size will work and can be designed by scaling the design parametrically.

Core Aesthetic: The motion profile is a "cascading wave” but can be programmed into other patterns. The prisms trigger sequentially (Prism 1, then Prism 2, etc.), creating a waterfall effect.

II. High-Level Strategy

### 1. Parametric Design Approach A custom software workflow will generate fabrication data

based on variable inputs (Image size, Prism count). This ensures the design is scalable and repeatable.

### 2. Direct Drive Topology The system will use 12 independent stepper motors with

programmable software acceleration curves. Hall Effect sensors will allow homing to zero position to correct any drift.

3. Silent Operation The installation is designed for gallery environments. Hardware selection prioritizes silent operation through "SilentStepStick" drivers, fanless power supplies, and high-resolution motors to eliminate vibration whine.

4.. Power Safety & Management

- Running the motors at 24V ensures high torque and speed.

- The Arduino cannot handle 24V directly and will be wired to 24V through an intermediate DC-DC Buck Power Converter 4-40V to 1.25-37V to step voltage down to 9V for the logic board. 9V allows headroom for brownouts when the motors kick in.
- Headroom: The system is calculated to draw ~80W under normal load. The 150W PSU provides ~50% safety headroom, ensuring cool, fanless operation.

III. Hardware Bill of Materials (BOM)

### 1. Electronics & Control

- Microcontroller: Arduino Mega 2560 R3 (Selected for 54 digital I/O pins to manage 12 sensors, probably 3 wires each, STEP, DIR, and EN)

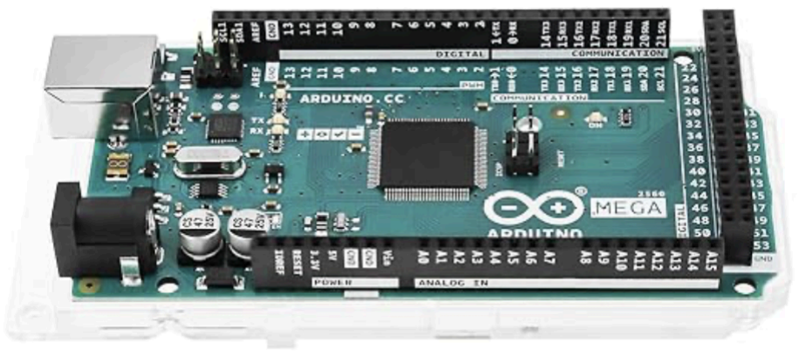
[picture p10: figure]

- . A Screw Terminal Block Breakout Shield Module on top will mean no soldering.

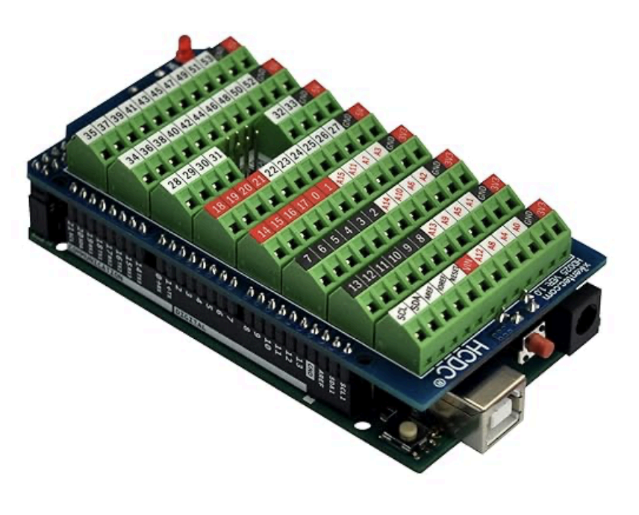
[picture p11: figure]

- Motor Drivers: Adafruit TMC2209 Stepper Motor Driver Breakout Board, with a 10-pin terminal block soldered on so wires can be screw-attached.

- Voltage Regulation (Logic): LM2596 DC-DC Buck Converter with LED Voltmeter Display (Steps 24V down to 9V for Arduino safety).

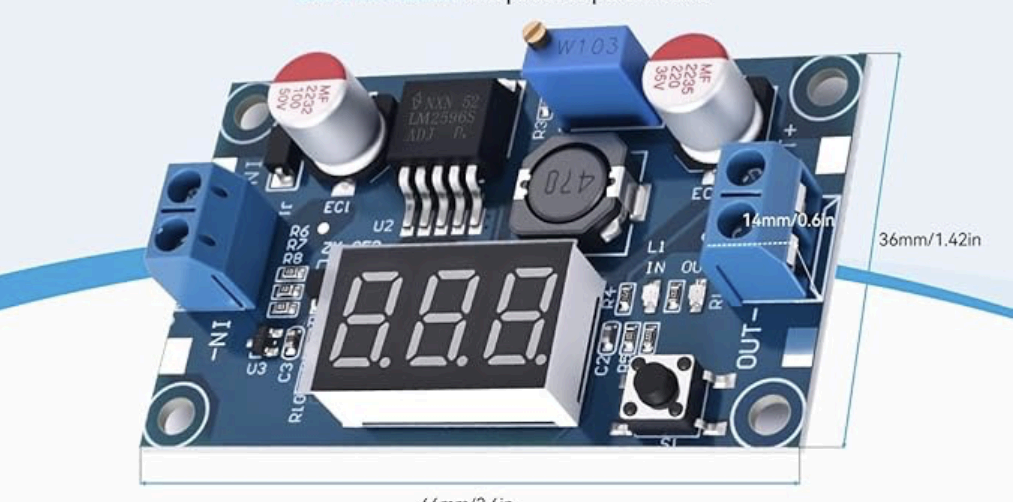
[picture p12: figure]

- 5V and GND from all 12 motors to be soldered to a common “bus” across the + and - rails on an Electrocookie PCB Prototyping Board. Gemini suggests I *might* need to install a Install the Noise Filter: a 100µF to 470µF Electrolytic Capacitor on the power rails at the "head" of the board (e.g., Row 1). Polarity: Ensure the capacitor's Negative stripe faces the GND rail. This would act as a localized reservoir, smoothing out the voltage dips caused when 12 motors accelerate simultaneously.

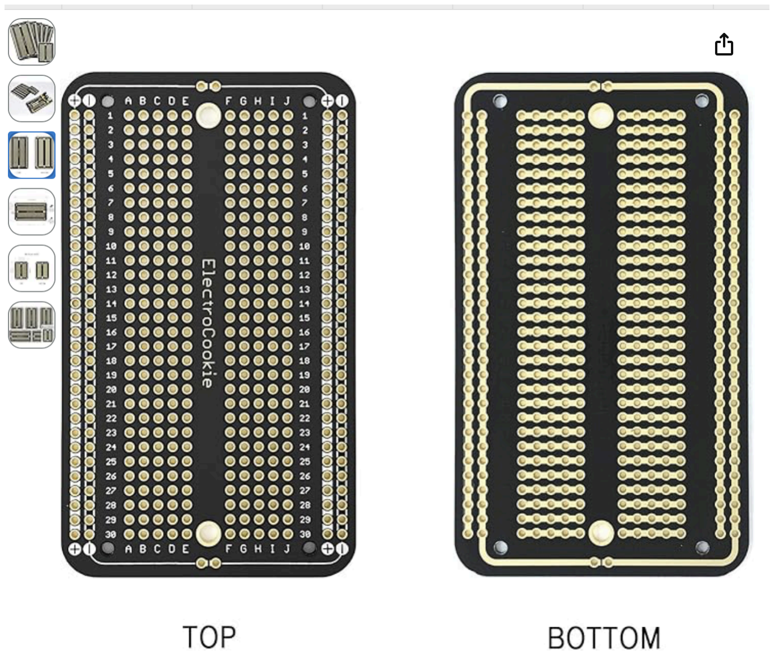
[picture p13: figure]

## 16 Amp 2x12 Position Terminal Block Distribution Module for AC DC

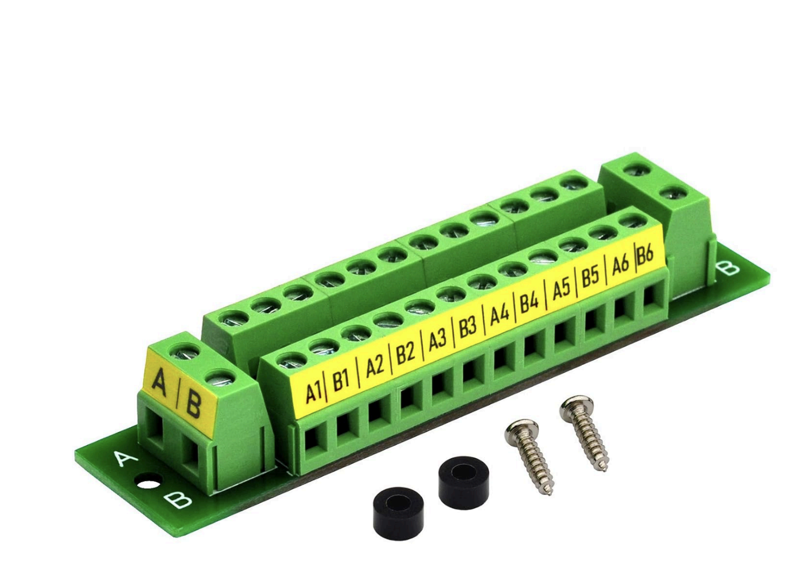
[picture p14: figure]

●

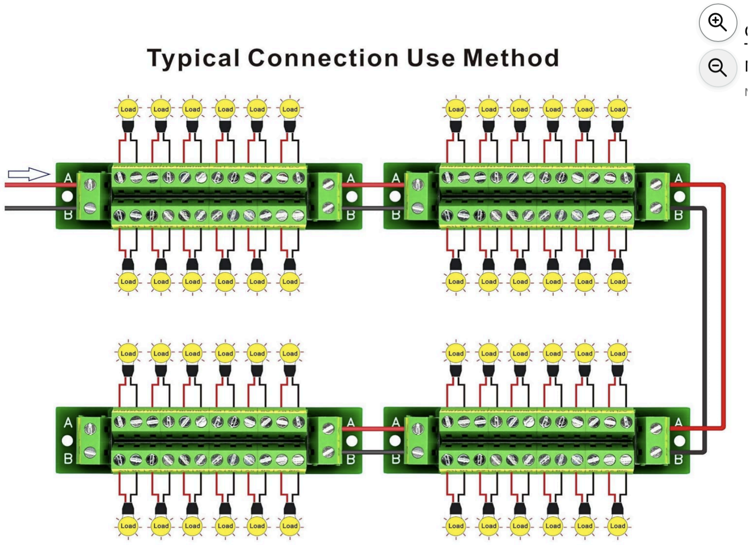
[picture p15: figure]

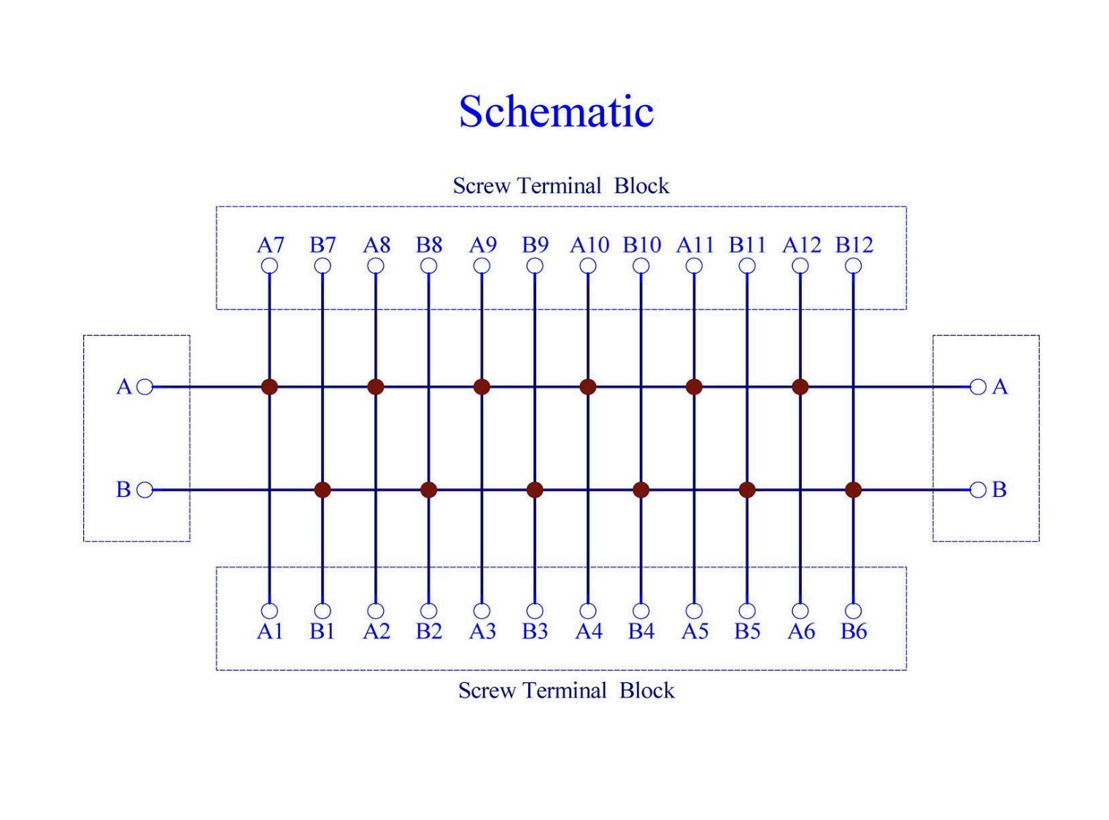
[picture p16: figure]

### 2. Motion System

- Motors: StepperOnline 17HM19-2004S Nema 17 Stepper Motors.
- Spec: 0.9° Step Angle (High Resolution), 46Ncm Torque, 2.0A Rated Current.
- Homing Sensors: A3144 Hall Effect Sensors (TO-92 Package). To be rigged in custom 3D mountsthat clip onto the motors.

### 3. Power System

- Primary Power Supply: Mean Well LRS-150-24.
- Spec: 24V DC, 6.5A, 150W.
- Feature: Fanless/Convection Cooled (Silent).

### 4. Wiring Plan

AC power goes:

Black > LRS-150-24 Power Supply “L”
White > LRS-150-24 Power Supply “N”
Green > LRS-150-24 Power Supply “Ground” (icon)

Then:

-V from LRS-150-24 > Motor Driver -+V from LRS-150-24 > Motor Driver +

Then:

-V from LRS-150-24 > Buck Converter VIN-+V from LRS-150-24 > Buck Converter VIN+

Then:

Buck Converter VOUT- > Arduino GND Buck Converter VOUT+ > Arduino VIN

TRIVISION PIN ASSIGNMENTS

Motor STEP pins (pins 35–46)

Motor 1: STEP pin 35 Motor 2: STEP pin 36 Motor 3: STEP pin 37 Motor 4: STEP pin 38 Motor 5: STEP pin 39 Motor 6: STEP pin 40 Motor 7: STEP pin 41 Motor 8: STEP pin 42 Motor 9: STEP pin 43 Motor 10: STEP pin 44 Motor 11: STEP pin 45 Motor 12: STEP pin 46

Motor DIR pins (pins 18–29)

Motor 1: DIR pin 18 Motor 2: DIR pin 19 Motor 3: DIR pin 20 Motor 4: DIR pin 21 Motor 5: DIR pin 22 Motor 6: DIR pin 23 Motor 7: DIR pin 24 Motor 8: DIR pin 25 Motor 9: DIR pin 26 Motor 10: DIR pin 27 Motor 11: DIR pin 28 Motor 12: DIR pin 29

Hall Effect sensor pins (pins 2–13)

Motor 1: Hall pin 2 Motor 2: Hall pin 3 Motor 3: Hall pin 4 Motor 4: Hall pin 5 Motor 5: Hall pin 6 Motor 6: Hall pin 7 Motor 7: Hall pin 8 Motor 8: Hall pin 9 Motor 9: Hall pin 10 Motor 10: Hall pin 11 Motor 11: Hall pin 12 Motor 12: Hall pin 13

### 5. Fabrication Materials

- Prism Substrate: 1/8"(0.118") Dibond (Aluminum Composite Material, ACM) - Matte White.
- Source: US Plastic Corp, Item #155783 (48" x 96" sheet).
- Prism Structure: 3-face hollow assembly with 3D printed top/bottom end-caps.
- Shafts will weigh about 4 lbs each and to avoid axial load on the steppers which are not rated for axial loads, I will need to transfer load onto stepper with axial thrust bearings (in Amazon cart)
- Next time you can get Stephen at Pegleg to cut it on his CNC.
- Ordering 8 black sheets, from

https://www.usplastic.com/catalog/item.aspx?itemid=155783

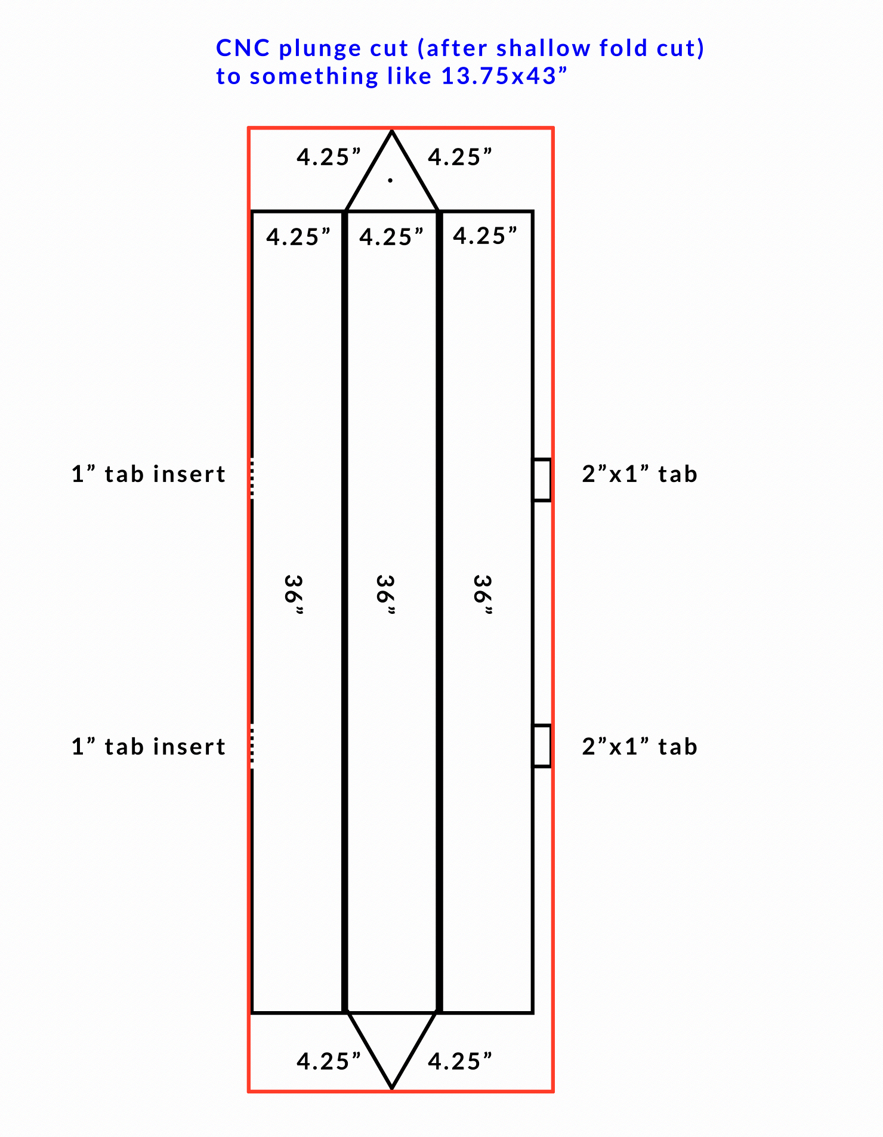
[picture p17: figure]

Want to put the prisms on a rectangle

Will need a 120º V-bit to router-cut the folds (outer sandwich layer of dibond)

12/11/25 ordered: Amana Tool RC-1146 CNC Insert V-Groove 120 Deg x 1-23/64 D x 25/64 CH x 1/4 SHK Router Bit

Z-Zero Strategy: Do not set your Z-zero to the top of the material. Set it to the spoilboard (machine bed).

- Your cut depth should be set to leave exactly 0.025" - 0.030" (0.6mm - 0.8mm) of material remaining.

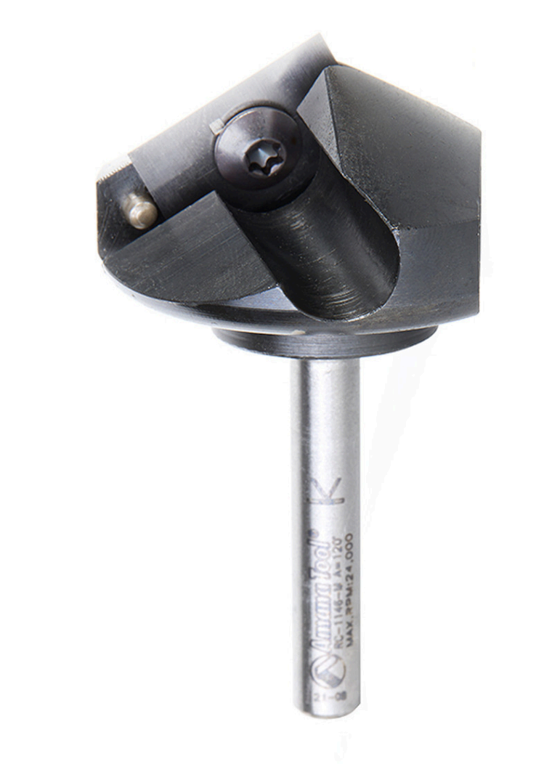
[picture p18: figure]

- Steel Shafts: 52” shafts (up to 56” is OK)

The Motor shaft is 5mm. The linear motion rod is 6mm. I will be using a 5mm to 6mm coupler: 5mm to 6mm Clamping Rigid Coupling, Set Screw Coupler

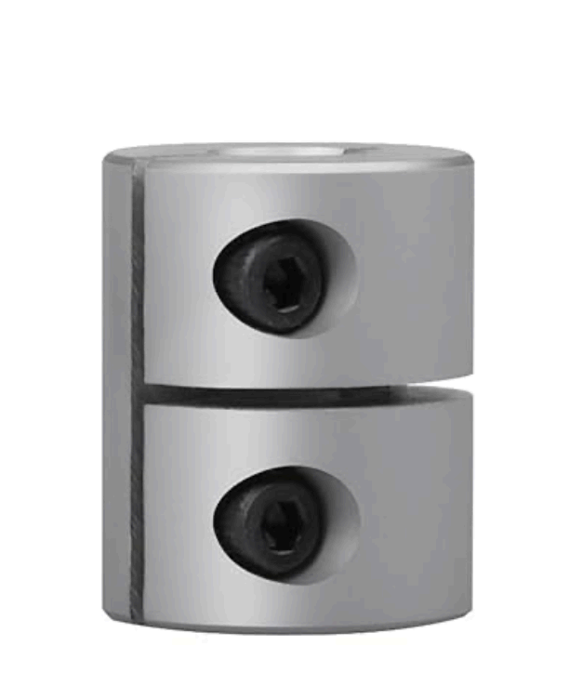
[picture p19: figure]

- Image Media: Hahnemuhle Baryta Luster paper (Adhered to ACM faces).
- Linear Motion Rods:
- Framing material:

6/4 × 7.5” white oak, surfaced (S4S):

You really need a minimum of 7.5” or you can’t getthe guts into it:

6/4 means 1.5” rough, surfaced down to 1.25” smooth

Black cut 3mm ACM ordered 12/12/25

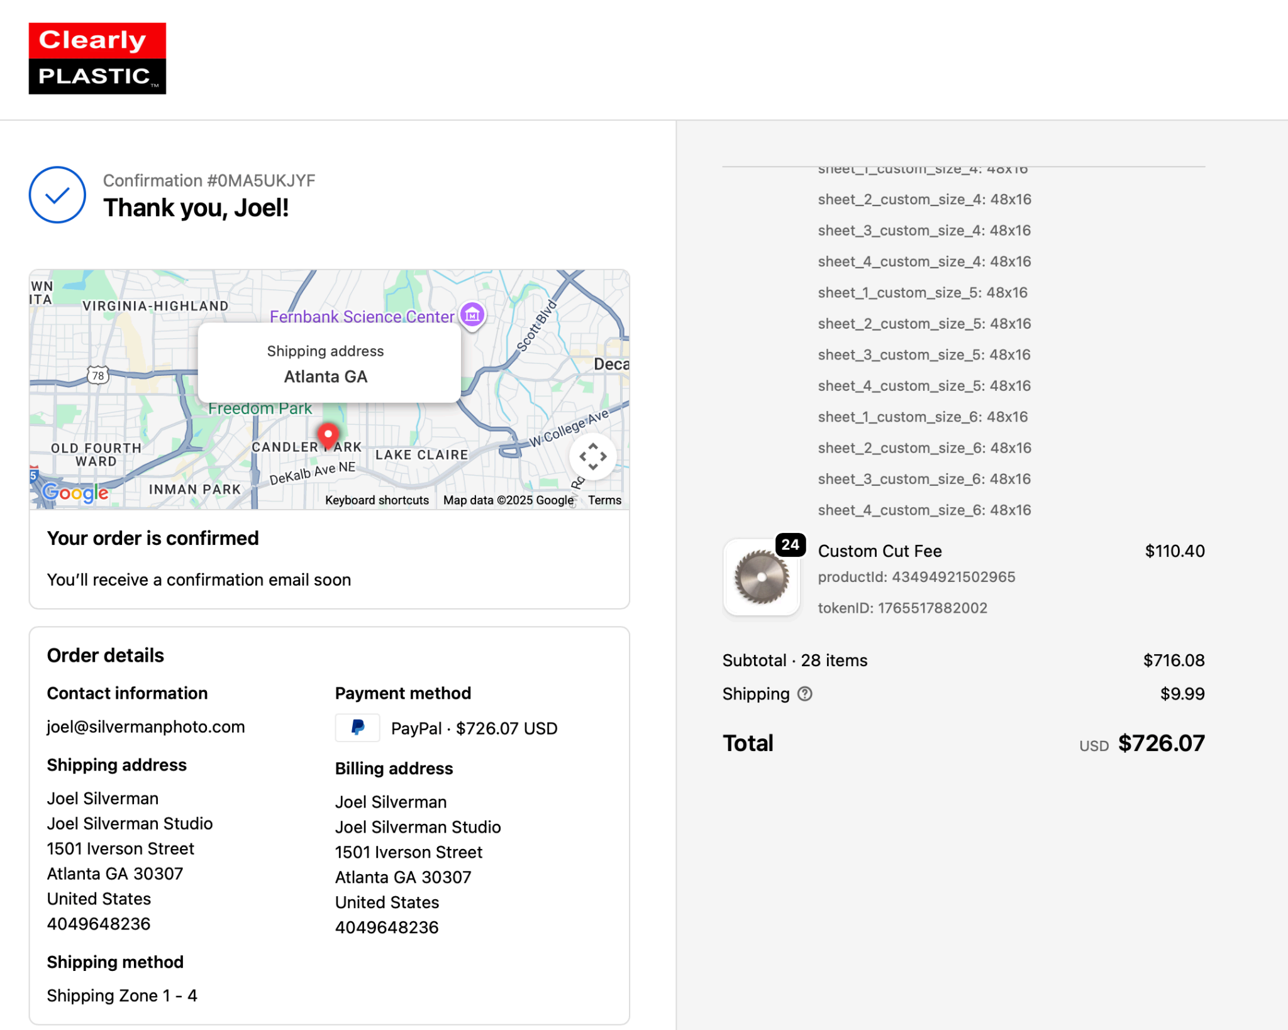
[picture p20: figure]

Motor #1

- VDD (pin 1) → Electrocookie 5V bus | RED
- GND (pin 2) → OONO B bus (GND) | YELLOW
- DIR (pin 3) → HCDC terminal 18 (column 5) | GREEN
- STEP (pin 4) → HCDC terminal 35 (column 8) | WHITE
- Hall brown wire (VCC) → Electrocookie 5V bus | BROWN
- Hall blue wire (GND) → OONO B GROUND bus or your Electrocookie GND rail BLUE
- Hall black wire (signal) → HCDC terminal 2 (column 3) BLACK

Motor #2

- VDD (pin 1) → Electrocookie 5V bus
- GND (pin 2) → OONO B bus (GND)
- DIR (pin 3) → HCDC terminal 19 (column 5)
- STEP (pin 4) → HCDC terminal 36 (column 7)
- Hall brown wire (VCC) → Electrocookie 5V bus
- Hall blue wire (GND) → OONO B GROUND bus or your Electrocookie GND rail
- Hall black wire (signal) → HCDC terminal 3 (column 3)

Motor #3

- VDD (pin 1) → Electrocookie 5V bus
- GND (pin 2) → OONO B bus (GND)
- DIR (pin 3) → HCDC terminal 20 (column 5)
- STEP (pin 4) → HCDC terminal 37 (column 8)
- Hall brown wire (VCC) → Electrocookie 5V bus
- Hall blue wire (GND) → OONO B GROUND bus or your Electrocookie GND rail
- Hall black wire (signal) → HCDC terminal 4 (column 3)

Motor #4

- VDD (pin 1) → Electrocookie 5V bus
- GND (pin 2) → OONO B bus (GND)
- DIR (pin 3) → HCDC terminal 21 (column 5)
- STEP (pin 4) → HCDC terminal 38 (column 7)
- Hall brown wire (VCC) → Electrocookie 5V bus
- Hall blue wire (GND) → OONO B GROUND bus or your Electrocookie GND rail

- Hall black wire (signal) → HCDC terminal 5 (column 3)

Motor #5

- VDD (pin 1) → Electrocookie 5V bus
- GND (pin 2) → OONO B bus (GND)
- DIR (pin 3) → HCDC terminal 22 (column 5)
- STEP (pin 4) → HCDC terminal 39 (column 8)
- Hall brown wire (VCC) → Electrocookie 5V bus
- Hall blue wire (GND) → OONO B GROUND bus or your Electrocookie GND rail
- Hall black wire (signal) → HCDC terminal 6 (column 3)

Motor #6

- VDD (pin 1) → Electrocookie 5V bus
- GND (pin 2) → OONO B bus (GND)
- DIR (pin 3) → HCDC terminal 23 (column 5)
- STEP (pin 4) → HCDC terminal 40 (column 7)
- Hall brown wire (VCC) → Electrocookie 5V bus
- Hall blue wire (GND) → OONO B GROUND bus or your Electrocookie GND rail
- Hall black wire (signal) → HCDC terminal 7 (column 3)

Motor #7 ← Hall sensors switch to column 2 starting here

- VDD (pin 1) → Electrocookie 5V bus
- GND (pin 2) → OONO B bus (GND)
- DIR (pin 3) → HCDC terminal 24 (column 5)
- STEP (pin 4) → HCDC terminal 41 (column 8)
- Hall brown wire (VCC) → Electrocookie 5V bus
- Hall blue wire (GND) → OONO B GROUND bus or your Electrocookie GND rail
- Hall black wire (signal) → HCDC terminal 8 (column 2)

Motor #8

- VDD (pin 1) → Electrocookie 5V bus
- GND (pin 2) → OONO B bus (GND)

- DIR (pin 3) → HCDC terminal 25 (column 5)
- STEP (pin 4) → HCDC terminal 42 (column 7)
- Hall brown wire (VCC) → Electrocookie 5V bus
- Hall blue wire (GND) → OONO B GROUND bus or your Electrocookie GND rail
- Hall black wire (signal) → HCDC terminal 9 (column 2)

Motor #9

- VDD (pin 1) → Electrocookie 5V bus
- GND (pin 2) → OONO B bus (GND)
- DIR (pin 3) → HCDC terminal 26 (column 5)
- STEP (pin 4) → HCDC terminal 43 (column 8)
- Hall brown wire (VCC) → Electrocookie 5V bus
- Hall blue wire (GND) → OONO B GROUND bus or your Electrocookie GND rail
- Hall black wire (signal) → HCDC terminal 10 (column 2)

Motor #10

- VDD (pin 1) → Electrocookie 5V bus
- GND (pin 2) → OONO B bus (GND)
- DIR (pin 3) → HCDC terminal 27 (column 5)
- STEP (pin 4) → HCDC terminal 44 (column 7)
- Hall brown wire (VCC) → Electrocookie 5V bus
- Hall blue wire (GND) → OONO B GROUND bus or your Electrocookie GND rail
- Hall black wire (signal) → HCDC terminal 11 (column 2)

Motor #11 ← DIR switches to column 6 starting here

- VDD (pin 1) → Electrocookie 5V bus
- GND (pin 2) → OONO B bus (GND)
- DIR (pin 3) → HCDC terminal 28 (column 6)
- STEP (pin 4) → HCDC terminal 45 (column 8)
- Hall brown wire (VCC) → Electrocookie 5V bus
- Hall blue wire (GND) → OONO B GROUND bus or your Electrocookie GND rail
- Hall black wire (signal) → HCDC terminal 12 (column 2)

Motor #12

- VDD (pin 1) → Electrocookie 5V bus
- GND (pin 2) → OONO B bus (GND)
- DIR (pin 3) → HCDC terminal 29 (column 6)
- STEP (pin 4) → HCDC terminal 46 (column 7)
- Hall brown wire (VCC) → Electrocookie 5V bus
- Hall blue wire (GND) → OONO B GROUND bus or your Electrocookie GND rail
- Hall black wire (signal) → HCDC terminal 13 (column 2)

Pins 5–10 on every driver (MS1, MS2, DIAG, INDEX, UART, EN) left unconnected.

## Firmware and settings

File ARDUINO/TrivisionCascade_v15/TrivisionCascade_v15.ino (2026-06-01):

/*
 * TrivisionCascade_v15 — 4-Motor 180° Cascade + Reverse
 * 
 * ANTI-STUTTER: Timer1 interrupt drives stepping at fixed 50µs tick.
 * All step timing is quantized to 50µs increments — perfectly uniform.
 * No polling jitter, no digitalWrite overhead in critical path.
 * 
 *   Motor 1: STEP=35 (PC2), DIR=18
 *   Motor 2: STEP=37 (PC0), DIR=19
 *   Motor 3: STEP=39 (PG2), DIR=20
 *   Motor 4: STEP=41 (PG0), DIR=21
 * 
 * Pattern:
 *   Cascade CW 180° (1→2→3→4, 1.25s stagger) → hold 3s →
 *   Reverse CCW 180° (4→3→2→1, 1.25s stagger) → hold 3s → repeat
 */

#include <avr/io.h>
#include <avr/interrupt.h>

#define NUM_MOTORS 4

// Direct port registers for STEP pins (much faster than digitalWrite)
// Pin 35 = PC2, Pin 37 = PC0, Pin 39 = PG2, Pin 41 = PG0
volatile uint8_t* stepPort[NUM_MOTORS] = {&PORTC, &PORTC, &PORTG, &PORTG};
const uint8_t stepBit[NUM_MOTORS]      = {2,      0,      2,      0};

const uint8_t dirPin[NUM_MOTORS] = {18, 19, 20, 21};

#define STEPS_180  1600L
#define CW   HIGH
#define CCW  LOW

#define CASCADE_OFFSET_MS  1250
#define HOLD_MS            3000

// Timing in TICKS (1 tick = 50µs)
#define RAMP_STEPS      250L
#define RAMP_START_TK   70U     // 3500µs / 50 = 70 ticks
#define CRUISE_TK       22U     // 1100µs / 50 = 22 ticks
#define SPEED_RANGE_TK  (RAMP_START_TK - CRUISE_TK)  // 48

// Pre-computed ramp tables in ticks
unsigned int rampUpTable[RAMP_STEPS];
unsigned int rampDownTable[RAMP_STEPS];

void buildRampTables() {
  for (long i = 0; i < RAMP_STEPS; i++) {
    long t2 = i * i;
    long denom = RAMP_STEPS * RAMP_STEPS;
    rampUpTable[i] = RAMP_START_TK - (unsigned int)((t2 * (long)SPEED_RANGE_TK) / denom);
    
    long j = RAMP_STEPS - 1 - i;
    long j2 = j * j;
    rampDownTable[i] = RAMP_START_TK - (unsigned int)((j2 * (long)SPEED_RANGE_TK) / denom);
  }
}

// --- Per-motor state (accessed from ISR — must be volatile) ---
struct MotorState {
  volatile long   targetSteps;
  volatile long   currentStep;
  volatile unsigned int ticksToNext;  // Ticks until next step
  volatile unsigned int tickCounter;  // Current countdown
  volatile bool   active;
};

volatile MotorState motor[NUM_MOTORS];

// --- Timer1 ISR: fires every 50µs --- 
ISR(TIMER1_COMPA_vect) {
  for (uint8_t m = 0; m < NUM_MOTORS; m++) {
    if (!motor[m].active) continue;
    
    motor[m].tickCounter--;
    
    if (motor[m].tickCounter == 0) {
      // STEP pulse — direct port, ~125ns
      *stepPort[m] |= (1 << stepBit[m]);   // HIGH
      // ~62.5ns per NOP at 16MHz, need ~2µs = 32 NOPs... 
      // but at this speed a few cycles is fine for TMC2209
      __asm__ __volatile__("nop\nnop\nnop\nnop\nnop\nnop\nnop\nnop\n"
                           "nop\nnop\nnop\nnop\nnop\nnop\nnop\nnop\n");
      *stepPort[m] &= ~(1 << stepBit[m]);  // LOW
      
      motor[m].currentStep++;
      
      if (motor[m].currentStep >= motor[m].targetSteps) {
        motor[m].active = false;
        continue;
      }
      
      // Look up next interval
      long i = motor[m].currentStep;
      long decelStart = STEPS_180 - RAMP_STEPS;
      
      if (i < RAMP_STEPS) {
        motor[m].ticksToNext = rampUpTable[i];
      } else if (i >= decelStart) {
        motor[m].ticksToNext = rampDownTable[i - decelStart];
      } else {
        motor[m].ticksToNext = CRUISE_TK;
      }
      
      motor[m].tickCounter = motor[m].ticksToNext;
    }
  }
}

// --- Sequencer (runs in main loop, non-time-critical) ---
enum State {
  STATE_CASCADE,
  STATE_HOLD_AFTER_FWD,
  STATE_REVERSE,
  STATE_HOLD_AFTER_REV
};

State currentState = STATE_CASCADE;
int motorsLaunched = 0;
unsigned long lastLaunchTime = 0;
unsigned long holdTimer = 0;

const int fwdOrder[NUM_MOTORS] = {0, 1, 2, 3};
const int revOrder[NUM_MOTORS] = {3, 2, 1, 0};

void launchMotor(int m, uint8_t dir) {
  digitalWrite(dirPin[m], dir);
  delayMicroseconds(5);
  
  // Set up motor state (disable interrupts briefly for atomic write)
  cli();
  motor[m].targetSteps = STEPS_180;
  motor[m].currentStep = 0;
  motor[m].ticksToNext = RAMP_START_TK;
  motor[m].tickCounter = RAMP_START_TK;
  motor[m].active = true;
  sei();
}

bool allDone() {
  for (int m = 0; m < NUM_MOTORS; m++) {
    if (motor[m].active) return false;
  }
  return true;
}

void setup() {
  Serial.begin(115200);
  while (!Serial) { ; }
  
  // Configure STEP pins via DDR (output mode)
  DDRC |= (1 << 2) | (1 << 0);  // Pins 35 (PC2), 37 (PC0)
  DDRG |= (1 << 2) | (1 << 0);  // Pins 39 (PG2), 41 (PG0)
  PORTC &= ~((1 << 2) | (1 << 0));  // Start LOW
  PORTG &= ~((1 << 2) | (1 << 0));
  
  for (int i = 0; i < NUM_MOTORS; i++) {
    pinMode(dirPin[i], OUTPUT);
    digitalWrite(dirPin[i], LOW);
    motor[i].active = false;
  }
  
  buildRampTables();
  
  // Configure Timer1 for 50µs interrupt (20kHz)
  // 16MHz / 8 prescaler = 2MHz, count to 100 = 50µs
  cli();
  TCCR1A = 0;
  TCCR1B = (1 << WGM12) | (1 << CS11);  // CTC mode, prescaler /8
  OCR1A = 99;                              // 50µs period
  TIMSK1 = (1 << OCIE1A);                 // Enable compare match interrupt
  sei();
  
  Serial.println(F("=== TrivisionCascade v15 — Timer ISR, Zero Jitter ==="));
  Serial.println(F("STEP={35,37,39,41} DIR={18,19,20,21}"));
  Serial.println(F("50us tick, direct port pulses, integer ramp tables"));
  Serial.println();
  
  delay(2000);
  
  motorsLaunched = 0;
  lastLaunchTime = millis();
  launchMotor(fwdOrder[0], CW);
  motorsLaunched = 1;
  Serial.println(F(">>> CASCADE CW 180 >>>"));
  Serial.println(F("  Motor 1 GO"));
}

void loop() {
  switch (currentState) {
    
    case STATE_CASCADE:
      if (motorsLaunched < NUM_MOTORS) {
        if (millis() - lastLaunchTime >= CASCADE_OFFSET_MS) {
          int m = fwdOrder[motorsLaunched];
          launchMotor(m, CW);
          Serial.print(F("  Motor "));
          Serial.println(m + 1);
          motorsLaunched++;
          lastLaunchTime = millis();
        }
      }
      if (motorsLaunched >= NUM_MOTORS && allDone()) {
        Serial.println(F("  Hold..."));
        holdTimer = millis();
        currentState = STATE_HOLD_AFTER_FWD;
      }
      break;
      
    case STATE_HOLD_AFTER_FWD:
      if (millis() - holdTimer >= HOLD_MS) {
        motorsLaunched = 0;
        lastLaunchTime = millis();
        launchMotor(revOrder[0], CCW);
        motorsLaunched = 1;
        Serial.println(F("<<< REVERSE CASCADE CCW 180 <<<"));
        Serial.print(F("  Motor "));
        Serial.println(revOrder[0] + 1);
        currentState = STATE_REVERSE;
      }
      break;
      
    case STATE_REVERSE:
      if (motorsLaunched < NUM_MOTORS) {
        if (millis() - lastLaunchTime >= CASCADE_OFFSET_MS) {
          int m = revOrder[motorsLaunched];
          launchMotor(m, CCW);
          Serial.print(F("  Motor "));
          Serial.println(m + 1);
          motorsLaunched++;
          lastLaunchTime = millis();
        }
      }
      if (motorsLaunched >= NUM_MOTORS && allDone()) {
        Serial.println(F("  Hold..."));
        holdTimer = millis();
        currentState = STATE_HOLD_AFTER_REV;
      }
      break;
      
    case STATE_HOLD_AFTER_REV:
      if (millis() - holdTimer >= HOLD_MS) {
        motorsLaunched = 0;
        lastLaunchTime = millis();
        launchMotor(fwdOrder[0], CW);
        motorsLaunched = 1;
        Serial.println();
        Serial.println(F(">>> CASCADE CW 180 >>>"));
        Serial.println(F("  Motor 1 GO"));
        currentState = STATE_CASCADE;
      }
      break;
  }
}

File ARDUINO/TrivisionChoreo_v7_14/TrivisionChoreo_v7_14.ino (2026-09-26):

/*
 * TrivisionChoreo v7.14
 *
 * ALL 12 MOTORS IN SYNC — 0.75 RPM CW
 * All launch simultaneously, wait, repeat forever.
 *
 * v7.14, forked from v7.13 on 2026-09-26: a direction table. A prism whose
 * motor turns the opposite way to the rest (marked R in TrivisionHWTest)
 * gets HIGH in dirCCW below and is turned the right way in software. As
 * shipped the table is all LOW, which drives every motor exactly as v7.13
 * did. The sketch also refuses to compile if its speed constants would pass
 * the authorised 1 RPM. Speed is unchanged.
 *
 * v7.13, forked from v7.10 on 2026-09-25 (v7.11 and v7.12 are the waterfall line).
 * A revolution is 3200 microsteps, which does not split into three equal
 * faces. v7.10 turned 1067 every time, so the prisms crept one microstep per
 * revolution, about 3.6 degrees an hour. The three faces now take 1067, 1066
 * and 1067 steps, so every third turn lands exactly where the first began.
 * Speed is unchanged.
 */

#include <avr/interrupt.h>
#include <avr/io.h>

#define NUM_MOTORS 12

// === PIN MAPPING ===
volatile uint8_t *stepPort[NUM_MOTORS] = {
    &PORTC, &PORTC, &PORTC,
    &PORTD,
    &PORTG, &PORTG, &PORTG,
    &PORTL, &PORTL, &PORTL, &PORTL, &PORTL
};
const uint8_t stepBit[NUM_MOTORS] = {2, 1, 0, 7, 2, 1, 0, 7, 6, 5, 4, 3};
const uint8_t dirPin[NUM_MOTORS] = {18, 19, 20, 21, 22, 23,
                                    24, 25, 26, 27, 28, 29};
// Level on each direction wire for a CCW turn; a CW turn writes the opposite.
// Paste the fourth block TrivisionHWTest prints over this line. Its R marks
// compare each prism with the first one tested, so check one prism by eye
// too: if every prism turns the wrong way, swap every LOW and HIGH.
const uint8_t dirCCW[NUM_MOTORS] = {LOW, LOW, LOW, LOW, LOW, LOW, LOW, LOW, LOW, LOW, LOW, LOW};

#define CCW LOW
#define CW  HIGH

#define MICRO_MULT 1
// 3200 / 3 is not whole: use 1067, 1066, 1067 so three faces total exactly one turn.
const long FACE_STEPS[3] = {1067L * MICRO_MULT, 1066L * MICRO_MULT, 1067L * MICRO_MULT};
uint8_t faceIdx[NUM_MOTORS];   // face each prism sits on, 0..2; zero at boot = square start

// === SPEED: 0.75 RPM ===
#define RAMP_STEPS 200L
#define RAMP_START_TK 1333U
#define CRUISE_TK 500U
#define SPEED_RANGE_TK (RAMP_START_TK - CRUISE_TK)

// Refuse to build anything over the authorised 1 RPM (50 us tick, 1/8 jumpers).
static_assert(MICRO_MULT == 1, "drivers are jumpered for 1/8 microstepping");
static_assert((long)CRUISE_TK * MICRO_MULT >= 375L, "CRUISE_TK exceeds the 1 RPM ceiling");
static_assert(RAMP_START_TK > CRUISE_TK, "ramp would accelerate backwards");

unsigned int rampUpTable[RAMP_STEPS];
unsigned int rampDownTable[RAMP_STEPS];

void buildRampTables() {
  for (long i = 0; i < RAMP_STEPS; i++) {
    long t2 = i * i;
    long denom = RAMP_STEPS * RAMP_STEPS;
    rampUpTable[i] =
        RAMP_START_TK - (unsigned int)((t2 * (long)SPEED_RANGE_TK) / denom);
    long j = RAMP_STEPS - 1 - i;
    long j2 = j * j;
    rampDownTable[i] =
        RAMP_START_TK - (unsigned int)((j2 * (long)SPEED_RANGE_TK) / denom);
  }
}

// === MOTOR STATE ===
struct MotorState {
  volatile long targetSteps;
  volatile long currentStep;
  volatile unsigned int ticksToNext;
  volatile unsigned int tickCounter;
  volatile bool active;
};
volatile MotorState motor[NUM_MOTORS];

// === TIMER1 ISR — 50µs tick ===
ISR(TIMER1_COMPA_vect) {
  for (uint8_t m = 0; m < NUM_MOTORS; m++) {
    if (!motor[m].active) continue;
    motor[m].tickCounter--;
    if (motor[m].tickCounter == 0) {
      *stepPort[m] |= (1 << stepBit[m]);
      __asm__ __volatile__("nop\nnop\nnop\nnop\nnop\nnop\nnop\nnop\n"
                           "nop\nnop\nnop\nnop\nnop\nnop\nnop\nnop\n");
      *stepPort[m] &= ~(1 << stepBit[m]);
      motor[m].currentStep++;
      if (motor[m].currentStep >= motor[m].targetSteps) {
        motor[m].active = false;
        continue;
      }
      long i = motor[m].currentStep;
      long decelStart = motor[m].targetSteps - RAMP_STEPS;
      if (i < RAMP_STEPS) {
        motor[m].ticksToNext = rampUpTable[i];
      } else if (i >= decelStart) {
        motor[m].ticksToNext = rampDownTable[i - decelStart];
      } else {
        motor[m].ticksToNext = CRUISE_TK;
      }
      motor[m].tickCounter = motor[m].ticksToNext;
    }
  }
}

// === HELPERS ===
void launchMotor(int m, uint8_t dir) {
  long steps;
  if (dir == CW) { steps = FACE_STEPS[faceIdx[m]]; faceIdx[m] = (faceIdx[m] + 1) % 3; }
  else           { faceIdx[m] = (faceIdx[m] + 2) % 3; steps = FACE_STEPS[faceIdx[m]]; }
  digitalWrite(dirPin[m], (dir == CCW) ? dirCCW[m] : !dirCCW[m]);
  delayMicroseconds(5);
  cli();
  motor[m].targetSteps = steps;
  motor[m].currentStep = 0;
  motor[m].ticksToNext = RAMP_START_TK;
  motor[m].tickCounter = RAMP_START_TK;
  motor[m].active = true;
  sei();
}

void waitForAll() {
  while (true) {
    bool done = true;
    for (int m = 0; m < NUM_MOTORS; m++) {
      if (motor[m].active) { done = false; break; }
    }
    if (done) return;
  }
}

// === SETUP ===
void setup() {
  Serial.begin(115200);
  while (!Serial) { ; }

  DDRC |= (1 << 2) | (1 << 1) | (1 << 0);
  DDRD |= (1 << 7);
  DDRG |= (1 << 2) | (1 << 1) | (1 << 0);
  DDRL |= (1 << 7) | (1 << 6) | (1 << 5) | (1 << 4) | (1 << 3);

  PORTC &= ~((1 << 2) | (1 << 1) | (1 << 0));
  PORTD &= ~(1 << 7);
  PORTG &= ~((1 << 2) | (1 << 1) | (1 << 0));
  PORTL &= ~((1 << 7) | (1 << 6) | (1 << 5) | (1 << 4) | (1 << 3));

  for (int i = 0; i < NUM_MOTORS; i++) {
    pinMode(dirPin[i], OUTPUT);
    digitalWrite(dirPin[i], LOW);
    motor[i].active = false;
  }

  buildRampTables();

  cli();
  TCCR1A = 0;
  TCCR1B = (1 << WGM12) | (1 << CS11);
  OCR1A = 99;
  TIMSK1 = (1 << OCIE1A);
  sei();

  Serial.println(F("=== TrivisionChoreo v7.14 — ALL SYNC ==="));
  Serial.println(F("0.75 RPM CW, all 12 motors simultaneous, loop"));
  Serial.println();

  delay(3000);
}

// === ALL 12 IN SYNC — loops forever ===
void loop() {
  // Launch all 12 at once
  for (int m = 0; m < NUM_MOTORS; m++) {
    launchMotor(m, CW);
  }
  Serial.print(F("ALL GO... "));

  waitForAll();
  Serial.println(F("done."));
}

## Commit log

2026-06-01 Baseline: Arduino motor code, CNC/Illustrator fabrication plans, 3D print files, docs
    Project-level CLAUDE.md added. Heavy binary media (Blender scenes, scans,
    renders — ~108 GB) excluded via .gitignore; this repo tracks code, fabrication
    plans, and documentation only.
    [02.13.26 Updated Inner Frame with Gap v4.dxf, A3144 Hall Effect Sensor.obj, BTT TMC2208 TMC2209 UART Stepper Driver.obj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]
2026-06-01 Correct CLAUDE.md: live Arduino sketches are v7_11 in MCP dir, archive is stale
2026-06-01 Mirror live Arduino sketches into ARDUINO/ archive (through v7_11)
    Re-sync from ~/Documents/Arduino_MCP_Sketches so the repo holds the real
    latest motor code: TrivisionCascade v01-v15, TrivisionChoreo v01-v07 and
    v7_0-v7_11, TrivisionHWTest v01-v03. CLAUDE.md updated to note both
    locations are now in sync.
2026-06-25 Add Fusion 360 MCP wiring + CAD version-diff lessons; commit CNC fabrication files
    - Document Fusion 360 MCP now wired into Claude Code (HTTP /mcp on 27182) in CLAUDE.md
    - Capture Fusion/CAD gotchas: third-party MCP stdout noise, two-pass STEP import +
    offset, sketch-text labels, and the geometry-based version-diff approach
    - Record the Trivision Billboard v1-vs-v2 comparison finding
    - Track new CNC fabrication files (Pegleg Trivision PLS .step, Origami Prism .dxf,
    updated no-tabs prism .svg)
    - update CLAUDE.md lessons learned
    [06.02.26 Pegleg Studio Trivision File PLS NEW.step, Silverman Dibond Origami Prism Stephen 36in v2.dxf]
2026-06-25 Add Fusion+Blender visualization workflow lessons to CLAUDE.md
    - Document running Fusion (canonical) + Blender (viz) MCPs together
    - Capture Fusion->Blender STL workflow + gotchas: mm/global_scale object-scale,
    view_layer.update() before matrix_parent_inverse, STL welds bodies, per-body
    export coordinate inconsistency, material-clobber-in-loop bug, UV-free box texturing
    - Note collections are not transform parents (root-empty pattern)
    - Record original-assembly frame material map (birch outside / oak inside / birch back)
    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
2026-07-12 docs: add Joel's artist statement to README — 1895 carte-de-visite origin, tabula scalata, trivision billboards
2026-07-26 v7.12 — fork of v7.11 as untouched baseline for post-rewire control work
    Exact copy of v7.11 (two-face waterfall, 0.75 RPM) with only the version
    string bumped. Created so the rewiring/motor-order work has a safe sketch
    to edit without overwriting v7.11.
    Verified on-chip contents: the board is running v7.10 (ALL SYNC), not
    v7.11 — confirmed by reading flash back and matching all 4002 bytes.
2026-07-26 HWTest v04 — motor identification tool for the post-rewire wiring check
    Serial-driven tool to discover which driver channel turns which prism after
    the 2026 rewiring. Move one channel at a time on command, record the prism
    that actually moved, and it emits corrected stepPort/stepBit/dirPin tables
    in true left-to-right prism order for pasting into the choreography sketch.
    Uses the proven v7 motion engine (Timer1 ISR, S-curve ramps, direct port
    writes) rather than AccelStepper, so motion matches the finished piece.
    0.75 RPM, one motor at a time, 120 degrees per move so prisms always land
    square. Hall sensor pins 2-13 untouched.
    Table-generation logic verified natively: identity mapping rep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
2026-07-26 docs: TMC2209 wiring + power reference — diagnoses the power-on pulsing
    Motor wire colours confirmed from the 17HM19-2004S datasheet Motor
    Connection table: black=A+=1A, green=A-=1B, red=B+=2A, blue=B-=2B.
    The + and - terminals are the 24V supply input, not motor wires.
    Diagnoses the all-motors-pulse-on-power-up symptom as power supply
    hiccup-mode overload, not a wiring fault: HWTest v04 issues no step
    pulses until commanded, all twelve pulse in unison (shared rail), and
    twelve motors holding at 2A/phase draw ~155W against the LRS-150-24's
    156W / 6.5A rating, leaving no headroom before the 110-140% trip.
2026-07-26 docs: confirm control-pin wiring and pin down the current-limit budget
    Verified against Joel's wiring manual and Adafruit's guide:
    - Arduino cable red=VDD, yellow=GND, green=DIR, white=STEP is as-designed.
    - EN left unconnected is correct: Adafruit states pulling EN high disables
    output, so floating leaves the driver enabled.
    - MS1/MS2 unconnected gives 1/8 microstepping, matching the sketch's
    3200-microsteps-per-rev arithmetic.
    The manual's own power budget is the corroborating evidence: it states the
    system draws ~80W with ~50% headroom on the 150W supply. 80W across twelve
    motors works out to 1.52 A/phase. At the pot's 2A maximum the same twelve
    motors draw ~155W / 6.4A against a 6.5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
2026-07-29 docs: slim the always-loaded project instructions by ~1,270 tokens
    Move the Fusion/CAD gotchas and the Fusion-to-Blender visualization workflow
    out of CLAUDE.md and into a new project skill, trivision-cad, so that ~5,200
    characters of task-specific technique loads on demand instead of in every
    session. Text moved verbatim; CLAUDE.md keeps a pointer naming the four traps.
    Drop the Working style section — all eight lines (scope, brevity, no apologies,
    full URLs, Futura not Arial) already load from the global instructions in every
    project, so this file was paying for them twice.
    Replace the hardcoded sketch-version list, which had gone stale (claimed 7.11
    and HWTest 03; actually 7.12 and 04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
2026-07-29 HWTest v05 — post-rewire smoke test; correct the current-dial arithmetic
    The sketch:
    - a plain channel number now nudges ten degrees out and back (~7s,
    ends square) instead of committing to a 38-second face change;
    the whole row walks in under two minutes
    - any serial byte stops a move, easing off over ~1 second; 'f' and
    'b' finish or back out a turn that was stopped part-way
    - rotation direction is recorded alongside prism position, and the
    printed tables now include the direction levels
    - full 120-degree face turns moved to the 't' commands
    - startup banner carries the current-dial precondition
    Speed unchanged: 0.75 RPM cruise, 25% under the 1 RPM ceiling.
    C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
2026-07-29 Reference: correct where to probe the current dial; find a free 3x standstill power saving
    Joel got no reading probing the dial's body. Two causes, both now documented
    from Adafruit's board file and the TMC2209 datasheet rev 1.09:
    - The dial is a Bourns 3314J. Its plastic body and adjustment slot are
    connected to nothing. The wiper is the single leg facing the green screw
    terminal; of the two legs facing the pin header, the one nearer the board
    edge sits at a fixed 1.16 V (a good 'is it alive' check) and the other is
    ground. Added a leg-by-leg table.
    - The board's coloured LEDs are logic indicators fed from the Arduino's 5 V
    (red/green = direction state, yellow = st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
2026-07-30 Add the TMC2209 stepper-driver datasheet to the Arduino folder
2026-09-25 Collision rule for neighbouring prisms, and one clearance check
    Review 2026-09 TRI-01. The simulators' geometry (face 4.2536 in, pitch
    4.45 in) lets neighbouring prisms' corners meet; the as-built pitch is not
    yet measured, so the rule is stated as a possibility, not a proven fault.
    - CLAUDE.md and the handoff: the two motion patterns known to be safe, the
    clearance check before upload, and the direction check after rewiring.
    - ARDUINO/prism_clearance.py: signed gap between two neighbours over every
    pair of angles (true distance, or minus the overlap depth), taking the
    measured face width and pitch; checks offsets, parked neighbours, single
    pairs and planned moves from a CSV.
    - The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
2026-09-25 HWTest v07 — stop recovery squares the prism; nothing else moves meanwhile
    Review 2026-09 TRI-02. Forked from v06; motion engine, ramps and speed
    unchanged (0.75 RPM cruise).
    - A stopped move is kept as one signed count of how far the prism sits
    from the square position it started from, summed over every leg it
    turned. b drives the count to zero; f drives it to the next face, or to
    zero for a nudge. v06 kept only the stopped leg, so f after a stopped
    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
2026-09-25 Power-on order: reset the Mega after 24 V so show sketches start powered
    Review 2026-09 TRI-03. Self-starting choreography sketches begin moving
    three seconds after boot whether or not 24 V is on, and the drivers ignore
    steps sent before it is, so the documented order (USB, banner, then 24 V)
    made the first turn end short. CLAUDE.md and the handoff's power-on
    sequence now add the reset step; test sketches that wait for a command
    need none.
2026-09-25 Choreo v7.13 — all-together turns no longer creep 3.6 degrees an hour
    Review 2026-09 TRI-04. Forked from v7.10 (all twelve together; v7.11 and
    v7.12 are the waterfall line). 3200 microsteps do not split into three
    equal faces, and 1067 every time overshot one microstep per revolution.
    The three faces now take 1067, 1066 and 1067 steps, tracked per prism, so
    every revolution totals exactly 3200. Speed unchanged (0.75 RPM cruise).
    CLAUDE.md's conversion math carries the rule for any sketch that keeps
    turning one way.
    Not uploaded.
    [TrivisionChoreo_v7_13.ino]
2026-09-26 HWTest v08 — short moves ease in and out; Both NL & CR no longer stops every move
    Forked from v07 (both sketch folders). Cruise stays 0.75 RPM.
    - Each step runs at the slower of the speed allowed by the steps taken and
    by the steps left, so a finish or back-out under 400 steps (50 for a
    nudge) no longer stops dead or halves its speed in one step. Moves of
    400 steps or more are unchanged. The down tables are gone (450 bytes RAM).
    - A newline that follows a command's carriage return is taken with the
    command, so it no longer reads as a stop request. A later newline still
    stops a move.
    - The corrected-tables printout says four blocks and names the
    choreography sketches that read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
    [TrivisionHWTest_v08.ino]
2026-09-26 Choreo v7.14 — direction table corrects reversed prisms; speed guard
    Forked from v7.13 (both sketch folders). 0.75 RPM, unchanged.
    - dirCCW holds the level each direction wire needs for a CCW turn, and
    launchMotor writes it (CW writes the opposite). Paste the fourth block
    that TrivisionHWTest prints over it. Shipped all LOW, which drives every
    motor exactly as v7.13 did: a host replay of 300 moves writes the same
    levels and totals 320,000 microsteps on every motor in both.
    - static_assert refuses a build over the authorised 1 RPM.
    Review findings TRI-06, TRI-07.
    [TrivisionChoreo_v7_14.ino]
2026-09-26 docs: current-state pointers, measured interrupt cost, slimmer CLAUDE.md
    - CLAUDE.md no longer names the February handoff as the source of truth or
    v7.11 as the latest sketch; it points to git log, the TMC2209 reference
    page, the arduino-expert skill and the serial banner.
    - The precedence line now matches the global rule: safety and speed
    invariants come first, and a conflict with Joel's instruction is raised
    once, then his instruction is followed.
    - Hardware inventory that the handoff and skill already hold is replaced by
    a pointer to the arduino-expert skill; the integer-only step-path rule
    and the board identifier stay. Blender and Fusion 360 MCP setup moves
    word for word i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
2026-09-26 Reference: step and direction lines do not float at power-on
    Adafruit's schematic for the 6121 breakout puts a 20 kOhm resistor from
    STEP to ground, and the TMC2209 holds DIR low internally (datasheet rev
    1.09, section 2.2). The page said both lines float, which overstated the
    second candidate cause of the power-on pulsing. It also notes that the
    reset press now ending the power-on order is covered by the same
    resistors.
    Review finding TRI-11 (declined: no resistor needs adding).
2026-09-26 Blender helpers build in a new scene instead of deleting the open one
    import_and_extrude.py and render_bottom_rail.py began by selecting and
    deleting every object in whatever scene was open. Both now run in a new,
    empty scene that shares the open scene's world, switch the window to it,
    and leave the open scene untouched. Checked headless in Blender 5.2.1 and
    5.3 on scratch copies: the factory scene keeps its camera, cube and light,
    the parts land in the new scene, and the render matches the old one.
    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
2026-09-26 README: status as of September 2026
    The status said twelve-motor firmware was still to come; the same engine
    the 4-motor prototype proved now drives all twelve prisms in the v7
    sketches. Blender-to-firmware conversion is described as planned, since
    today's patterns are written by hand.
    Review finding TRI-15.
2026-10-17 System map: how motion gets from Blender and the Mac to the twelve prisms
    Standing architecture diagram (Mermaid source plus rendered PNG), embedded
    in the README, with a Makefile to re-render and check it. Planned parts
    (Blender step-table export, hall-sensor homing, 24 V sense jumper) are drawn
    dashed and labelled PLANNED.
2026-10-17 Choreo v7.15 — paste all four test-tool tables together; banner lists reversed prisms
2026-10-17 HWTest v09 — a stop sent during a pause is caught before the next move
2026-10-17 CCW-1rpm-test v7.16 — all twelve together, one gentle full turn at 1 RPM CCW on command
2026-10-17 CLAUDE.md: current state after the October audit and the 1 RPM sync test
2026-10-17 CLAUDE.md: the board runs HWTest v04; arduino-cli 1.5.1
2026-10-17 CLAUDE.md: motor engine audit result
